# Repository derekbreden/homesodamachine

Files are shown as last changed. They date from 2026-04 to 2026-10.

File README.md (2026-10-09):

# Home Soda Machine

A kitchen appliance that dispenses real Pepsi-made diet soda — Diet Mountain Dew, Diet Pepsi, Pepsi Zero Sugar — cold and carbonated, from a faucet. Turn the handle, soda comes out.

The public face of the project is **[homesodamachine.com](https://homesodamachine.com)** — what this is, the 3D viewer, and a single signup form to be notified when units are available. This repository is the working substrate behind that.

The prototype that proves the dispense path is in Derek's kitchen today — a Lilium under-counter carbonator with peristaltic pumps injecting flavor concentrate into the dispensed water. The project's biography lives in [`biography/`](/biography/) — [`2026-04-05.md`](/biography/2026-04-05.md) (origin story: failed SodaStream, the business-license wall, the AI design wall) and [`2026-05-23.md`](/biography/2026-05-23.md) (vision into work: welding, marketing, the engineering).

The product under development is an integrated under-counter soda machine — custom-fabricated 316L stainless carbonator, harvested ice-maker refrigeration loop, foam-insulated cold core, two flavor reservoirs, all behind a single 120 VAC cord and one CO2 line. The machine as it stands, subsystem by subsystem: [`hardware/README.md`](/hardware/README.md). Where it is going and what done looks like: [`future/README.md`](/future/README.md). Who it is for: [`marketing/target-market.md`](/marketing/target-market.md); the cabinet it has to fit: [`marketing/install-envelope.md`](/marketing/install-envelope.md).

## What's where

| Path | Contents |
|---|---|
| [`biography/`](/biography/) | Project biography by chapter — `2026-04-05.md` (founding), `2026-05-23.md` (vision into work) |
| [`hardware/`](/hardware/) | The integrated soda machine under development — CAD scripts, [`bom.md`](/hardware/ledger/bom.md), [`purchases.md`](/hardware/ledger/purchases.md), [`assembly/`](/hardware/assembly/) procedures, printed parts, wiring schedules |
| [`firmware/`](/firmware/) | ESP32 + ESP32-S3 firmware: the main board, the machine display and the faucet display of the soda machine under development, the bare-board bench rig, and the weld rotator — see [`firmware/README.md`](/firmware/README.md) for which tree runs where. |
| [`web/`](/web/) | homesodamachine.com — Node server, CAD viewer — see [`web/README.md`](/web/README.md) |
| [`ios/`](/ios/) | iOS companion app (BLE bridge, settings, usage stats) |
| [`android/`](/android/) | Android companion app |
| [`brand/`](brand/README.md) | On tap faucet identity, Big Blue palette, app icons, wordmarks, and shared asset generation |
| [`marketing/`](/marketing/) | Target market analysis, [Lincoln sales and installation](marketing/lincoln/README.md), unboxing brief, video scripts |
| [`business/`](/business/) | Incorporation, regulatory (UL 943, ASSE 1022) |
| [`future/`](/future/) | Where the project is going — the vision and the plan in [`README.md`](/future/README.md), and the desires not yet committed to plans in [`pie-in-the-sky/`](/future/pie-in-the-sky/) |
| [`tools/`](/tools/) | CadQuery venv, render scripts, measurement utilities |

Agents and collaborators landing in this repo: [`CLAUDE.md`](/CLAUDE.md) is the entry point.

## License

MIT

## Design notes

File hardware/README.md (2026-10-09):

# Hardware

The soda machine's physical design — the integrated under-counter unit that consolidates carbonator, refrigeration, flavor reservoirs, pumps, valves, and electronics into one enclosure.

This page is the design narrative and the map. The narrative describes the machine subsystem by subsystem and points at the companion docs and part directories that specify each one; it carries no specifics itself. Where the machine is going, and what done looks like, is [`/future/README.md`](/future/README.md). Who it is for is [`/marketing/target-market.md`](/marketing/target-market.md).

## The soda machine

The soda machine is an integrated under-counter unit. It packs the carbonator, its refrigeration loop, both flavor reservoirs, the pumps and valves, and the electronics into one enclosure behind a single 120 VAC cord, with the tap-water inlet at the rear and the CO2 cylinder standing beside the machine on a short tether. The prototype under the counter has proven the dispense path — two flavors of Pepsi-made concentrate injected into cold carbonated water, press the lever and soda comes out. What this build adds is the cold carbonated water itself: the machine carbonates and refrigerates its own. What stays above the counter is a faucet and a small display; the rest is under the sink.

This is the **thin** machine: tall and narrow, built around one bound. The cold core is turned a quarter turn so its short axis runs across the cabinet, and nothing else in the machine is as wide, so nothing else sets the width. What the turn buys is a column of height above and ahead of the core. The space it is built for is in [`/marketing/install-envelope.md`](/marketing/install-envelope.md).

Read the machine from its cold center outward and from the back of the box forward. A **cold core** fills the back-bottom of the enclosure — a stainless carbonator, an evaporator coil wound around it, and the two flavor reservoirs nested in foam around it, where they pre-chill. Forward of the core are the compressor and the pumps and valves; above it, the electronics and the water deck; over them the flavor funnel. The carbonated-water line runs straight up through the countertop to the faucet. The sections below take the cold core **inside out** and the enclosure **back to front**.

### Carbonation

The carbonator is a custom 316L stainless pressure vessel standing vertically, with four NPT ports in two identical plates. The top water-inlet elbow carries a small jet that sends filtered tap water through the CO2 headspace into the water below. CO2 enters through a plain bottom port, carbonated water leaves through the other bottom port, and a dedicated pressure-relief valve guards the top. Temperature, CO2 pressure, jet mixing and refill timing together determine the carbonation delivered to the glass. The water level inside is read without piercing it — a magnet rides on an internal rod and external reed switches see it through the wall.

The selected diaphragm pump is the received [G Ganen sample](/hardware/reference/g-ganen-pump/README.md). The enclosure uses its measured rigid housing and ports, with four identical nominal 7 mm rubber feet at the selected rail-end stations. Installed discharge points toward enclosure −X. [Print readiness](/hardware/printed-parts/enclosure/print-readiness.md) records what the complete enclosure trial prints and what the bench has accepted. The Mean Well IRM-90-12ST supply is the current reference. The [water-inlet jet](/hardware/assembly/water-inlet-jet.md) is a drilled 316 cap welded onto the existing elbow's male tip; its fit and full root fusion require physical qualification. [Acceptance and burn-in](/hardware/assembly/acceptance-and-burn-in.md) establish actual refill, restart and first- and successive-glass performance. [Carbonation Plan B](/future/carbonation-plan-b.md) maps a measured shortfall to a conditional change.

Carbonator fabrication, the hydro-test, the passivation, and the working pressure are in [`/hardware/assembly/pressure-vessel.md`](/hardware/assembly/pressure-vessel.md), with the end-cap cut parts in [`/hardware/cut-parts/carbonation/`](/hardware/cut-parts/carbonation/) and the bench fixture that turns the tube under the welder in [`/hardware/assembly/weld-rotation-rig.md`](/hardware/assembly/weld-rotation-rig.md). The full water and CO2 plumbing — every fitting, the check valves, the beverage backflow preventer, the two-stage CO2 regulation — is in [`/hardware/assembly/internal-plumbing.md`](/hardware/assembly/internal-plumbing.md), with the joints the foam buries in [`/hardware/assembly/cold-core.md`](/hardware/assembly/cold-core.md), and the valve-and-fluid topology in [`/hardware/topology/fluid-topology.md`](/hardware/topology/fluid-topology.md). The parts themselves, and their order status, are in [`/hardware/ledger/`](/hardware/ledger/).

The [gun orientation scene](/hardware/assembly/weld-position.md) shows the tube,
recessed endcap and gun, with roll about the tangent at the joint.

### Refrigeration

The cold comes from a refrigeration loop harvested from a countertop ice maker — its compressor, condenser, fan, capillary tube, and drier kept in service, with a copper coil wound around the carbonator doing the evaporator's work. Firmware cycles the compressor against temperatures read at the carbonator wall and the coil, with a freeze cutout. The refrigerant is a natural hydrocarbon, vented and recharged through a permanent service valve.

The teardown, the recharge and its charge mass, and the brazing safety are in [`/hardware/assembly/refrigerant-loop.md`](/hardware/assembly/refrigerant-loop.md); the donor units and the keep-or-discard plan in [`/hardware/reference/ice-maker/README.md`](/hardware/reference/ice-maker/README.md); the coil winding in [`/hardware/printed-parts/cold-core/coil-mandrel/`](/hardware/printed-parts/cold-core/coil-mandrel/). The refrigerant's regulatory standing is in [`/business/regulatory.md`](/business/regulatory.md).

### Cold core (inside out)

Read it inside out: the carbonator; the evaporator coil bonded to its outside; the foam shell's inner wall foamed against the coil; the two flavor reservoirs nested in that foam, where they pre-chill in the gradient between the near-freezing core and the cabinet air; the foam shell's outer wall, foamed again. The reservoirs are vented printed parts, not pressure vessels — sized for a refill of concentrate, and level-sensed the same way the carbonator is.

The carbonator and reservoirs use the [one-piece ASA Aero float](/hardware/printed-parts/cold-core/magnetic-float/all-aero/README.md), 36 × 28 mm with an inserted RC62 at its midplane. Its [shared guide datums and reed calibration](/hardware/printed-parts/cold-core/magnetic-float/all-aero/installation.md) set the 20 mm inside-wall rod spacing. This is a trial article; pressure life and liquid compatibility remain unqualified.

The layered build is in [`/hardware/assembly/cold-core.md`](/hardware/assembly/cold-core.md). The shells and the pour-in-place foam are in [`/hardware/printed-parts/cold-core/foam-shell/`](/hardware/printed-parts/cold-core/foam-shell/), with [`foam-cap/`](/hardware/printed-parts/cold-core/foam-cap/) and [`foam-assembly/`](/hardware/printed-parts/cold-core/foam-assembly/). The reservoirs — their floor and bulkhead, their filtered vent, their reed-and-float level column, their watertight printing — are in [`/hardware/printed-parts/cold-core/reservoir/`](/hardware/printed-parts/cold-core/reservoir/). The relief-valve shroud is in [`prv-shroud/`](/hardware/printed-parts/cold-core/prv-shroud/).

### Flavor

Two peristaltic pumps draw flavor from the chilled reservoirs and inject it at the gooseneck alongside the carbonated water; each flavor is primed and valve-locked between pours. The pumps run forward only, and a valve manifold selects the fill, dispense, and clean-in-place paths. Four pump-side tees float on their tubes, their branch collars journalled in the tee wall; four bowed tee-to-valve stubs and four tee-side hairpin ends flex as the tees travel while their other ends remain on the fixed valve rows. Each reservoir fills from the shared silicone funnel on top, nominally [455 mL](/hardware/printed-parts/zone-c/funnel/README.md). The clean cycle runs in software.

The canonical valve-state truth table, with the manifold and tray diagrams beside it, is in [`/hardware/topology/fluid-topology.md`](/hardware/topology/fluid-topology.md). How a valve is held on a printed face is in [`/hardware/printed-parts/valve-seat/`](/hardware/printed-parts/valve-seat/); the pumps in [`/hardware/printed-parts/enclosure/pump-tray/`](/hardware/printed-parts/enclosure/pump-tray/) and the pump cartridge they ride out on in [`enclosure/`](/hardware/printed-parts/enclosure/enclosure/); the funnel in [`/hardware/printed-parts/zone-c/`](/hardware/printed-parts/zone-c/). The four bowed stubs' figures in the topology are exposed developed paths across sleeve-face gaps, not tube-blank cut lengths. The valve-side insertion depths are bench-fit as each tube blank is made. Derek’s [physical collet observations](/hardware/reference/tee-connector/README.md#observed-push-connect-action) establish the release and relocking action; the assembled unit’s dry cycle checks release and reconnection. The reservoir level-sensing pattern is in [`/hardware/printed-parts/cold-core/reservoir/level-sensing.md`](/hardware/printed-parts/cold-core/reservoir/level-sensing.md). One pump serving N flavors on a single line, switching by reverse-purge and re-prime, is a desire captured in [`/future/pie-in-the-sky/single-pump-flavor-switching.md`](/future/pie-in-the-sky/single-pump-flavor-switching.md).

### Enclosure (back to front)

The enclosure stands in the cabinet beneath the sink, in the slot beside the disposal that [`/marketing/install-envelope.md`](/marketing/install-envelope.md) describes. Read it back to front. The cold core is yawed a quarter turn and seated in the back-bottom corner, flat on the floor and flush at the side walls; the diaphragm pump runs front to back over its lid and is what the rear wall stands off. The band above the core is the service bay: the diaphragm pump down the middle, the electronics bay against the +X wall, the water deck in the −X lane. The compressor stands upright on the floor at the front, bolted to the slab, with the condenser beside it and the **machine corridor** behind — the band the refrigerant loop turns in on its way to the core, and the one the manifold's cross-machine lines run along. The condenser's airflow crosses the cabinet: in through the grille on one side face, out the other. The top-front arris is rounded wall to wall, with the machine display let into its sloped plane; the funnel takes the top wall's full width behind it. The cabinet prints as four telescoping quadrants that cross-pin with screws from the side faces. The pump cartridge and its top clamp ride in the front bay; behind them a fixed release plate fronts four tee journals. At release the collets bear fully depressed against the fixed plate; at connected they stand fully extended, 0.5 mm from the plate. Pulling the cartridge draws the tees to the plate, which holds the collets open while the four tubes leave. No face is a panel of its own. The **+Y wall of back-top** lands every connection the machine makes to the world — the water inlet, the CO2 inlet, the AC cord, the signal jack and the umbilical — one row above the deck. The front wall's one opening is the bay, and the pump cartridge's own face closes it.

The silhouette, the zoning, and what each face carries are in [`/hardware/printed-parts/enclosure/README.md`](/hardware/printed-parts/enclosure/README.md). The split-printable box and its joint are in [`enclosure/`](/hardware/printed-parts/enclosure/enclosure/), the packed assembly in [`manifold-layout/enclosure_assembly.py`](/hardware/manifold-layout/enclosure_assembly.py). The +Y wall of back-top's connection inventory is in [`y-wall-of-back-top/`](/hardware/printed-parts/enclosure/y-wall-of-back-top/), the serialized nameplate in [`nameplate/`](/hardware/printed-parts/enclosure/nameplate/). The mechanical assembly of the whole is in [`/hardware/assembly/enclosure-mechanical.md`](/hardware/assembly/enclosure-mechanical.md). What placement answers to is [`design-pressures.md`](/hardware/design-pressures.md).

### Electronics and power

A single 120 VAC cord enters the +Y wall of back-top. A 12 V supply makes the low-voltage bus that runs the diaphragm pump, the peristaltic pumps, the solenoid valves, the condenser fan, the displays, and the sensors; the logic rails are made on-board. The compressor switches on the AC side; the fan and the 12 V loads switch low-side, firmware-gated. The whole electronics bay — the PSU, the relays, the AC distribution and ground bus, the main board, and the DC distribution — stands down the +X wall in the band above the cold core, feet on the foam cap's lid, each module turned so its own mounting plane faces the wall and bolted to printed bosses reaching in off it, with the water deck in the lane beside them. There is no tray under any of it.

The run-by-run AC schedule is in [`/hardware/wiring/ac-wiring-schedule.md`](/hardware/wiring/ac-wiring-schedule.md), and the power, pinout, and valve-control topology in [`/hardware/wiring/`](/hardware/wiring/). The bench build of the electronics, and the wiring procedure that follows it, are in [`/hardware/assembly/electronics-bay.md`](/hardware/assembly/electronics-bay.md) and [`/hardware/assembly/wiring.md`](/hardware/assembly/wiring.md). The main board — one JLCPCB-assembled PCBA, no plug-in modules — is in [`/hardware/pcb/`](/hardware/pcb/); its bench mount, which does not ship, is in [`/hardware/printed-parts/electronics/`](/hardware/printed-parts/electronics/).

### Safety

Simply having a 1022 already puts us ahead of most of these products. A 1022 that vents into the bowl at the faucet would be the only home arrangement I've found where the vent's discharge is defined, drained and visible.

Three hazards are designed around independently. The compressor's terminal block and clip-on PTC start relay remain under the R-600a donor's own moulded cover; the hydrocarbon refrigerant is watched by a gas sensor low in the cabinet that gates the remotely mounted compressor relay, and backstopped by a thermal fuse in the compressor's own AC primary. The carbonic-acid backflow path is held by a beverage backflow preventer whose vent runs through a dedicated white 4 mm LLDPE line to a visible outlet over the sink bowl near the faucet joint. The plumbed machine's mains and ground-fault posture, the refrigerant charge limits, and the unit markings are consolidated in one place.

The whole safety and regulatory posture is in [`/business/regulatory.md`](/business/regulatory.md), which carries the qualification still owed on the retained donor terminal cover; the refrigerant-handling and brazing safety in [`/hardware/assembly/refrigerant-loop.md`](/hardware/assembly/refrigerant-loop.md) under "Safety". An integrated ground-fault (GFCI) module is a deferred desire, captured in [`/future/pie-in-the-sky/gfci.md`](/future/pie-in-the-sky/gfci.md).

### User-facing surfaces

Above the counter, the faucet lever pours, and the faucet display at the end of the gooseneck shows the selected flavor and switches it by touch. On the machine's rounded top-front, angled up toward the standing user, the machine display is the configuration surface, over the flat face that is the pump cartridge's own. Flavor is refilled from the top: pour into the silicone funnel. For cleaning, lift it straight out; its plug slides off the raw tube stub held in the drain elbow. Press the plug into the frame to refit it until the brim seats. The pumps are reached from the front instead — pull the pump cartridge and both are in your hand. The pumps connect through a magnetic pogo contact pair between the cartridge's flat back and the bay bulkhead, which parts as the cartridge leaves and mates as it seats; the fixed lead returns to J13 through the cable clip near the ridge wall's +X edge. To return the cartridge, present the four pump tubes through the release plate and seat it.

The faucet's printed parts — the faucet shell, display cover, above-counter plate, above-counter gasket, o-ring and [umbilical organizer](/hardware/printed-parts/faucet/umbilical-organizer/README.md) — are in [`/hardware/printed-parts/faucet/`](/hardware/printed-parts/faucet/), over the cut [`under-counter plate`](/hardware/cut-parts/faucet/). The displays' reference geometry is in [`/hardware/reference/waveshare-43b-display/`](/hardware/reference/waveshare-43b-display/) and [`/hardware/reference/touch-flo-faucet/`](/hardware/reference/touch-flo-faucet/); the facet the machine display is let into, and the pump cartridge under it, in [`/hardware/printed-parts/enclosure/enclosure/README.md`](/hardware/printed-parts/enclosure/enclosure/README.md); the funnel in [`/hardware/printed-parts/zone-c/README.md`](/hardware/printed-parts/zone-c/README.md). What the customer does on install day is drawn in the [install guide](/hardware/install-guide/README.md). The behavior these surfaces drive is firmware — [`/firmware/`](/firmware/).

### Build order

The sequence the whole machine is built in is the dependency chain of the procedure docs in [`/hardware/assembly/`](/hardware/assembly/), with the skilled-hand tasks summarized in [`handwork.md`](/hardware/assembly/handwork.md): carbonator, cold core, refrigerant loop, then three benches that run in parallel with that chain and feed the chassis — cable assemblies, electronics bay, faucet and umbilical — then the loose-front-top manifold, enclosure closure, the remaining internal plumbing, wiring, commissioning, burn-in, pack and ship.

[`internal-plumbing.md`](/hardware/assembly/internal-plumbing.md) §3 begins before enclosure closure because `enclosure-front-top` is the assembly fixture. Its order is bare tees loaded into the tee wall's journals; aft valves raised from the underside and pressed into their sockets; fore valves and four bowed flex stubs. The pump cartridge goes in only after the box closes. The rest of internal plumbing follows [`enclosure-mechanical.md`](/hardware/assembly/enclosure-mechanical.md), and [`wiring.md`](/hardware/assembly/wiring.md) takes a chassis that already carries its plumbing. [Letter shop guides](/hardware/assembly/guides/README.md) illustrate drilling and cutting, molds, refrigeration, and the carbonator weld operation.

The Lillium-fed build, the flavor side in the enclosure with none of the cold core, is [`lillium-cutover.md`](/hardware/assembly/lillium-cutover.md).

## Layout

| Path | What's there |
|---|---|
| [`design-pressures.md`](/hardware/design-pressures.md) | What the machine is optimised for and what it is not. Placement decisions answer to this: volume and assemblability are optimised, field service and disassembly are not. |
| [`concerns.md`](/hardware/concerns.md) | Every concern raised about the machine, by stage of its life: answered, with its evidence, or open, with what exists so far. |
| [`mechanical-qualification/`](/hardware/mechanical-qualification/README.md) | Current mechanical evidence and qualification needs: fasteners, joint locations, deposited print structure, retained clamp force, handling and endurance. Links accepted physical records and controlled profile comparisons. |
| [`ledger/`](/hardware/ledger/) | Bookkeeping. [`purchases.md`](/hardware/ledger/purchases.md) is the source-of-truth capex ledger; [`bom.md`](/hardware/ledger/bom.md) (per-unit parts), [`tools.md`](/hardware/ledger/tools.md) (active tooling), and [`inventory.md`](/hardware/ledger/inventory.md) (spares / abandoned / donor / diagnostic stock) are views over it. Three more price time rather than parts: [`labor.md`](/hardware/ledger/labor.md) (attended minutes per unit), [`machine-time.md`](/hardware/ledger/machine-time.md) (hours a machine is occupied per unit), and [`build-time.md`](/hardware/ledger/build-time.md) (seconds a generator run takes, which is what a change to this repo costs rather than what a soda machine costs). |
| [`assembly/`](/hardware/assembly/) | Production procedures, one doc per subsystem, plus [`handwork.md`](/hardware/assembly/handwork.md) (the skilled-hand task summary). |
| [`service/`](/hardware/service/) | Procedures run on a finished machine rather than a bench: [`pump-replacement.md`](/hardware/service/pump-replacement.md) and the dry cycle it runs first. |
| [`printed-parts/`](/hardware/printed-parts/) | FDM parts: CadQuery generators (`*.py`) + exported `*.step` + sidecars. Includes `cadlib/` (shared geometry helpers), `cold-core/`, `electronics/`, `enclosure/`, `faucet/`, `refrigeration/`, `valve-seat/`, `zone-c/`. |
| [`cut-parts/`](/hardware/cut-parts/) | Laser-cut sheet parts: `*.dxf` outlines + sidecars (carbonation end-caps, under-counter plate). |
| [`manifold-layout/`](/hardware/manifold-layout/), [`cold-core-layout/`](/hardware/cold-core-layout/), [`faucet-layout/`](/hardware/faucet-layout/) | The assemblies the parts above stand in, each written as one multi-solid STEP: the packed machine, the core one frame further in, and the above-counter column. `/3d` browses the tree these head — the machine and the faucet as its two cards, and the machine stands the core's own bodies, so opening it is already being inside the core. |
| [`off-the-shelf-parts/`](/hardware/off-the-shelf-parts/) | Reference geometry for purchased parts modelled into assemblies. |
| [`reference/`](/hardware/reference/) | Imported / harvested reference STEPs (factory faucet, solenoid, ice-maker, fittings). Not fabricated by this project — no sidecars. |
| [`topology/`](/hardware/topology/) | Fluid + valve topology, including the canonical valve-state truth table. |
| [`wiring/`](/hardware/wiring/) | Wiring schedules, pinouts, and power topology diagrams. |
| [`battery-backup/`](/hardware/battery-backup/) | Mains-outage dispense ride-through: an architecture the BOM, wiring and firmware do not yet carry. |
| [`install-guide/`](/hardware/install-guide/) | The bound install guide that ships in the install kit beside it. |
| [`snapshots/`](/hardware/snapshots/) | Dated, point-in-time records (build-readiness audit, tapping plan, fill-from-funnel plan). **Frozen, not living docs** — re-run produces a fresh dated file rather than editing these. |
| [`scripts/`](/hardware/scripts/) | Project Python tooling. The instruments: [`probe.py`](/hardware/scripts/probe.py) asks the placed machine a geometry question instead of reasoning about it — where a body is, how close two come, what a volume runs into, how far a line runs, where there is room for one, what a pick copied out of the viewer names, and where a piece of a routed line can stand; [`fit.py`](/hardware/scripts/fit.py) asks the same of a body that is not placed yet, carried to a candidate pose; [`lanes.py`](/hardware/scripts/lanes.py) enumerates every corridor a run could take between its two fixed mouths at a stated clearance floor, holding every body still, and reports each one's tube, corners, tightest clearance, lowest z and the sub-assembly its legs lie on without ranking them. Each carries a `selftest`. Then `_cadq_export.py` (the shared atomic STEP/DXF/PDF export helper imported tree-wide) and the doc-sync / totals generators that maintain the `ledger/` docs. |

## Where the solids are

    node web/scripts/fetch-cad-artifacts.mjs              # the solids the pointer file names, onto this disk

A generated `.step` is on this disk and in no index. [`cad-artifacts.json`](/hardware/cad-artifacts.json) names each one by sha256, the release asset carrying them, and the commit each came from — `source.commit` for the bundle, and an `unproven` entry naming the uncommitted paths a pack was cut beside and the members they reach, since a solid mid-edit still ships. [`tools/cad-artifacts/pack.py`](/tools/cad-artifacts/pack.py) builds and points at one, and the deploy runs the fetch above (`render.yaml`). A build cuts them too, so a checkout that runs one needs no fetch. The three harvested solids under [`reference/`](/hardware/reference/) have no builder here and are in the index.

## The design loop

    source → changed solid → local view → pointer moved → /3d

The local render and the deployed viewer are two stops on one geometry path. [`tools/look.sh`](/tools/look.sh) opens a generated STEP from this disk through the same `/3d` viewer the headless renderers drive. [`pack.py --write`](/tools/cad-artifacts/pack.py) packages the generated solids on this disk; after its pointer file is committed and pushed, Render fetches that bundle and `/3d` serves it. Each commit runs [`publish_now.py`](/tools/publish_now.py) from `.githooks/post-commit`, which publishes the solids on this disk and moves the pointer file. The solid an agent judges locally is the solid that goes in front of Derek.

A repository-wide build is not a viewing boundary. A generator, focused Bazel target, [`probe.py`](/hardware/scripts/probe.py), or [`fit.py`](/hardware/scripts/fit.py) answers the current design question; the next local picture follows it immediately. Broader builds and checks answer broader questions when those questions arise. The iteration speed that matters is the time from an edit to the next informed look — first by the agent, then by Derek.

## What a build costs

    bazelisk build //:everything                          # every generator whose inputs moved
    tools/cad-venv/bin/python tools/bazel/sync_tree.py    # what the tree does not carry yet

For a focused dirty-tree build:

    targets=$(tools/cad-venv/bin/python tools/bazel/affected.py --artifacts)
    bazel build $targets
    tools/cad-venv/bin/python tools/bazel/sync_tree.py --write --solids-only --targets "$targets"

ONE ACTION PER STEP, EACH HOLDING WHAT IT DECLARED AND NOTHING ELSE. What it declared is what
a run of it was watched reading — `tools/bazel/trace_inputs.py` installs an audit hook, runs
the generator once, and keeps every path under this repo it opened, including the ones handed
to a tool it starts. The median step declares nine files; `_cable_assemblies_sync` declares
six, and the assembly syncs that import the machine to reach its constants declare eighty. The
graph is `tools/bazel/graph.json`; `tools/bazel/gen_build.py` writes `BUILD.bazel` from it.

A step is usually one generator. Four are several: `docgen` lets more than one script keep a
doc's `[value](NAME)` figures, each managing its own names, so `faucet_shell.py` and
`under_counter_plate.py` both write `ASSEMBLY.md` and are one action. `bazel` needs
one action per file, and `inventory._together` is what groups them.

`bazel-bin/` is where a build lands. The tree commits its docs and holds ignored solids long
enough for the content-addressed bundle to publish them, because a reader at `/3d` and a shop
printing a part both need the same bytes. `sync_tree.py` carries every declared output over;
a tree it has nothing to say about is a tree holding the artifacts its sources make.

WHAT AN EDIT COSTS IS THE STEPS THAT DECLARED THE FILE, and that is a count, not a guess.
`_boxes.py` is declared by 95 of the 99 steps, so it is the worst case the tree has:

| an edit to `_boxes.py` | steps | wall |
|---|---|---|
| a comment written into it | **1** — `pysrc` alone | **1.8 s** |
| a line of code | 95 | 406 s |

| | wall |
|---|---|
| the whole tree, nothing moved | **0.4 s**, no action run |
| whether anything is owed — `--check_up_to_date` | **0.3 s**, no action run |
| every step rerun, the kept work standing | 88 s, 41 s of critical path |
| every step rerun, the kept work regenerating | 386 s, 219 s of critical path |

The last two are the same 99 actions and differ only in whether `.cache/` already holds the
shapes they cut. A geometry edit pays the second on the bodies it moved and the first on the
rest. All of these were taken on a quiet machine; a reading taken while another build is
running is roughly half speed for want of cores, and is a ceiling rather than a figure.

A BYTE IS WHAT DECIDES A RERUN, and a comment is not a byte a step reads. `tools/bazel/pysrc.py`
lays every Python source down with its comments out of it — a line carrying no code is gone,
and the code lines come through verbatim and in order — and the steps declare that copy rather
than the file. So writing a comment moves one short action, its output lands on the bytes Bazel
already built against, and nothing under it runs. What comes out parses to what went in, and
`pysrc` asserts that per file before it writes: the same reading `_realized.code_digest` takes,
put where Bazel can see it.

The 32 generators whose own docstrings hold `[value](NAME)` figures are handed their file raw,
because the run rewrites what it was given and `sync_tree` carries that back into the tree. A
step that actually starts Node is also handed `:node-packages`, which globs `tools/render/` and
`web/` in whole.

A line number in a sandbox traceback is that copy's, not the tree's. The line it names is in
the tree, found by its text.

AND AN ACTION HOLDS THE KEPT WORK. `.cache/` is the shapes `_realized` keeps, the meshes
`_meshes` tessellates and the optimal boxes `_boxes` measures; `.bazelrc` mounts it into every
action and `_realized.key` mixes in `HSM_INPUT_DIGEST`, a hash over the solids the action was
given. The import walk covers the Python and that digest covers the other half — a solid loaded
off disk is not an import, and `enclosure.py` makes no `import_step` call of its own while its
action declares 28 solids it reaches through what it imports.

A SOLID ONE GENERATOR CUTS AND THE NEXT LOADS IS AN EDGE LIKE ANY OTHER HERE. `foam_assembly`
reads `foam-cap-top.step` from `//:foam-cap` and `enclosure_assembly` reads
`foam-assembly.step` from `//:foam-assembly`; neither can fall back to the older copy fetched
from the artifact pointer file. OCCT opens these below Python, so `_cadq_export.import_step` records the
paths and `gen_build.py` resolves each one to its producer output.

A picture is the same picture every run. Every renderer in `tools/render/` reads the frame
back off the canvas in the task that drew it (`browser.js` `frameBuffer` carries why), so
nothing here is a race and a redraw of unmoved geometry lands byte-identical — eight runs of
one scene and eight of one part, one hash each.

A view of any STEP, from any angle, is `tools/look.sh` — drawn when someone asks for one, so
there is none of it in the tree to go stale.

WHAT THE ACTIONS RUN WITH IS THE MACHINE'S, not the tree's. `tools/cad-venv` holds the
interpreter and its packages, `node_modules` the renderer's, and `rsvg-convert` and `blender`
come off the brew prefix — `.gitignore` holds the first two and the last two are not in the
repo at all. `.bazelrc` names both roots as mounts and puts them on every action's PATH. A
checkout on another machine builds when those are installed there and not before.

AND `blender` INSTALLED IS NOT THE WHOLE OF WHAT THE LINE ART NEEDS. The Freestyle SVG
exporter is a downloadable extension, not part of Blender, and everything `_blender_scene.py`
and `sieve_scene.py` ask it for is a property it ADDS to the scene when it registers —
`linestyle.use_export_strokes`, and the `scene.svg_export` group. A Blender without it is a
Blender the line art cannot run on:

```
blender --background --online-mode --command extension install -s -e freestyle_svg_exporter
```

`BLENDER_USER_RESOURCES` decides where that lands and where a run looks for it, so `.bazelrc`
passes the variable through to every action rather than stating a path — unset on a machine
whose extensions are already under the default user path. Both scene scripts check the enable
and exit non-zero naming the extension, because `addon_utils.enable` does not raise when the
module is absent: it prints one line and returns None, and the miss surfaces a hundred lines
later as an `AttributeError` with Blender itself exiting 0.

TWO THINGS THE BUILD DOES NOT GUARANTEE, both named where they stand:

- **A `.step.mesh` is not a declared output.** `_cadq_export` tessellates best-effort — a
  payload must never break an export — and a Bazel output is one the action must produce or
  fail. The two are opposite promises. So no action writes one: `sync_tree` carries what a
  target declares, the payload is in nothing's `outs`, and `.bazelrc` sets
  `HSM_SKIP_MESH_PAYLOAD` for every action rather than tessellating a file the sandbox
  discards. The runs that keep the tree's payloads are a hand run and the dev-server watcher.
- **`//:render-scenes` carries `local` and is not sandboxed.** `render-step-posed.js` stands
  the viewer on loopback and photographs it with a headless browser, and that page loads
  `occt-import-js` off a CDN — so drawing a scene reaches the public network for a library this
  tree does not carry. Vendoring it is what would make the action hermetic. It is the one
  action here whose inputs are not all declared.

Inside one run:

| phase | wall |
|---|---|
| derive + audit — `build_enclosure_assembly`, then the card | 8.7 s |
| — of which `_boxes.boxed`, 1372 calls against the disk-kept six | 0.55 s |
| OCCT STEP write, 21 MB | 1.3 s |
| canonicalise — renumber 382,700 entities | 3.7 s |
| tessellate the `.mesh` payload | 1.6 s |
| one thumbnail, drawn off the payload | 3 s |
| one thumbnail, drawn off the STEP with no payload beside it | 16 s |

The export and render rows are timed at `189e46a0`; the two derive rows at `7101d08c`.

## Part metadata sidecars

Every fabricated part has a JSON sidecar next to it recording material + thickness + process. The dev viewer reads these to extrude DXF outlines into real 3D plates; tooling and future agents should treat them as the source of truth for material/thickness queries.

### Naming

`<full-filename>.json`, in the same directory as the part:

```
cut-parts/foo/foo.dxf
cut-parts/foo/foo.dxf.json       ← sidecar

printed-parts/bar/bar.step
printed-parts/bar/bar.step.json  ← sidecar
```

The sidecar filename always carries the original extension (`.dxf.json`, `.step.json`), so a directory holding both a `.dxf` and a `.step` of the same basename has no collision.

### Format

```json
{
  "thickness_mm": 1.524,
  "material": "304 stainless steel",
  "process": "laser-cut",
  "notes": "optional free-form context"
}
```

- **`thickness_mm`** (number, required) — for DXF cuts this drives the viewer's `ExtrudeGeometry` so the flat outline becomes a real plate. For STEP prints / shells / tubes it is the wall thickness, kept for documentation and future tooling (the STEP geometry itself already carries full 3D shape).
- **`material`** (string) — free-form, in the spec language you'd put in a quote or order: `"304 stainless steel"`, `"316 stainless steel"`, `"PETG"`, `"PET-GF"`, `"Bambu TPU 90A"`, etc.
- **`process`** (string) — free-form. Common values: `laser-cut`, `3D-print`, `tube-bend`. Add new values as needed.
- **`notes`** (string, optional) — anything else worth knowing: stock size, supplier, why the spec was chosen, tap-engagement counts.

Pull values from the part's generator-script docstring when one exists; otherwise use the spec you ordered or printed against.

### When to update

- **Adding a part:** add the matching `.json` sidecar in the same commit. The viewer treats a DXF without a sidecar as zero-thickness and falls back to wireframe.
- **Changing thickness or material:** update the sidecar in the same commit as the geometry. The dev server's watcher picks up sidecar changes and hot-reloads with the new thickness, no page refresh needed.
- **Renaming or moving a part:** rename/move the sidecar alongside the geometry file.

### Harvested reference parts

[`reference/`](/hardware/reference/) holds imported reference STEPs (the harvested Westbrass, valve internals) this project does not fabricate. These get no sidecars — they're multi-material, externally-spec'd parts kept only for spatial reference.

### Where this is consumed

- The dev viewer (`web/`) extrudes DXF outlines using `thickness_mm`; STEP rendering ignores the sidecar (the STEP is already 3D). See `web/lib/viewer-routes.js` (`/api/dxf` returns each DXF's path alongside its sidecar fields).
- Future tooling (BOM generators, render-dxf, manufacturing quotes) should read the sidecar rather than re-parsing docstrings.

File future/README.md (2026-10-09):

# Future

This directory is what the project is for and where it is going. This page carries the
vision and the plan; [`pie-in-the-sky/`](/future/pie-in-the-sky/) carries the desires that
have no plan yet. Everything else in the tree describes what is: the machine as it stands
is [`/hardware/README.md`](/hardware/README.md), who it is for is
[`/marketing/target-market.md`](/marketing/target-market.md).

## What the machine is for

A person walks to their kitchen sink, turns a handle, and a glass fills with Diet Mountain
Dew — as cold and as carbonated as the can, and colder and fizzier than most. They never
buy a can again. That is the whole of it.

The alternatives on the market do not do this. Canned soda means hauling twenty-four to
forty-eight cans a week from store to car to kitchen, and running out. Home carbonation
means carbonating warm water into a bottle that is flat before it reaches the glass, which
is why the machines sell enormously and get used twice. The gap is refrigeration: cold water
holds carbonation and warm water does not, and no consumer product refrigerates and
carbonates and dispenses on demand.

The flavor is not a substitute. Pepsi sells its own formulations as SodaStream-compatible
concentrate to anyone, so a machine that injects it dispenses the brand rather than an
approximation of it. What is missing is the machine.

## What done looks like

Three marks, in order. Each one is finished when a physical thing exists, not when a
document says so.

**One. The machine pours in Derek's kitchen.** One appliance, built end to end from this
tree — carbonator welded and hydro-tested, loop brazed and charged, core foamed, box
printed, board flashed, faucet plumbed through the counter — standing under his own sink
where the prototype stands now, pouring both flavors daily for a month without being
opened. Until this exists the tree describes a machine that has never been built once.

**Two. Ten machines in ten kitchens.** Ring 1 of
[`target-market.md`](/marketing/target-market.md) "The internal plan": the first ten units
go to people Derek knows, or one degree out, at whatever price moves them. The deliverable
is not the revenue. It is ten machines in daily use by people who did not build them,
generating failures Derek did not predict, and supplier relationships priced at a run of
fifty. Ring 1 closes when the tenth unit is installed and the design is tighter than what
unit one received. Each plate those units carry is lettered and coded with the
unit's own address — [Unit links](/future/unit-links.md).

The [Lincoln sales and installation track](/marketing/lincoln/README.md) explores local
advertising, founder delivery and installation, and nearby service alongside the relationship
rings. It shares the build queue and founder hours; its local offer and pilot size remain
proposals.

**Three. The Founder Edition run.** Units 001–050 at $7,500, numbered and signed, built one
at a time by one person. This is the public plan and the price anchor; it opens when the
machine has been built enough times that the build is boring, and it closes when the
fiftieth is committed.

## What stands between here and the first mark

The build follows the order in [`/hardware/README.md`](/hardware/README.md) "Build
order". First-unit fabrication and performance qualification are part of that work.

| Owed | Where the procedure is |
|---|---|
| The water-inlet jet cap fitted, welded and physically qualified on the existing elbow | [`water-inlet-jet.md`](/hardware/assembly/water-inlet-jet.md) |
| The first production closure weld, PT-checked, hydro-tested, passivated | [`pressure-vessel.md`](/hardware/assembly/pressure-vessel.md) |
| The first refrigerant loop brazed to a carbonator and charged | [`refrigerant-loop.md`](/hardware/assembly/refrigerant-loop.md) |
| The first cold core foamed in place around a welded carbonator | [`cold-core.md`](/hardware/assembly/cold-core.md) |
| The whole enclosure printed as one set of quadrants that close on each other | [`enclosure-mechanical.md`](/hardware/assembly/enclosure-mechanical.md) |
| One appliance plumbed, wired, commissioned, and burned in for eight hours | [`internal-plumbing.md`](/hardware/assembly/internal-plumbing.md), [`wiring.md`](/hardware/assembly/wiring.md), [`acceptance-and-burn-in.md`](/hardware/assembly/acceptance-and-burn-in.md) |
| Measured refill and restart, strong carbonation in the first and successive cold glasses, and recorded recovery | [`acceptance-and-burn-in.md`](/hardware/assembly/acceptance-and-burn-in.md), [`carbonation-plan-b.md`](/future/carbonation-plan-b.md), [`model.md`](/future/model.md) |
| One faucet installed through a real countertop by the customer's own path | [`quickstart/`](/hardware/quickstart/) |

The procedures identify the remaining physical qualifications, including jet-cap fit
and weld fusion, gas-check placement, and carbonation under actual refill conditions.
The first unit uses the G Ganen pump, IRM-90 supply and enclosure. The conditional
responses in [Carbonation Plan B](/future/carbonation-plan-b.md) apply only if the
measurements identify a shortfall. The work and machine time are tracked in
[`labor.md`](/hardware/ledger/labor.md) and
[`machine-time.md`](/hardware/ledger/machine-time.md).

## What the tree is for

The repository is a manufacturing system, and that is deliberate. It cuts the parts, prices
them, names them, and publishes what it holds, so that the fiftieth unit costs what the
ledgers say and not what the first one taught. A generator that draws a part also writes its
own documentation, its figures, and the card the operator builds from, so a figure in a
document is read off the part rather than typed beside it. A check runs when someone asks
the question it answers, not on every commit or build.

The risk this creates is the obvious one. A tree that can be improved forever will be, and
improving it feels like progress in a way that welding does not. The marks above exist to
name the difference. Nothing in this repository is finished by a commit.

## No dates

There are none here, and there are none anywhere in this tree. A mark is finished when the
physical thing exists, and the record of when that happened is written after it happens —
[`updates/`](/updates/) and [`biography/`](/biography/) are where it lands. What this page
holds is the order the marks come in and what each one is owed, which is a plan; a date
would be a guess dressed as one.

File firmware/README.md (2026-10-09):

# Firmware

Five source trees, each its own PlatformIO environment in [`/platformio.ini`](/platformio.ini), each running on its own board.

| Tree | Env | Runs on | Machine |
|---|---|---|---|
| `src_appliance/` | `appliance` | the main board's WROOM (U1) | the soda machine |
| `src_pcba_bench/` | `pcba_bench` | the main board's WROOM (U1) | none — a bare board on the bench |
| `src_front/` | `esp32s3_front` | Waveshare ESP32-S3-Touch-LCD-4.3B | the soda machine |
| `src_faucet/` | `esp32s3_faucet` | Waveshare ESP32-S3-Touch-LCD-1.47 | the soda machine |
| `src_weld_rotator/` | `weld_rotator` | ESP32-DevKitC-32E + DM542T | the cap-weld bench fixture |

Two of them run on the main board, and only one of the two ships inside a machine.

**`src_appliance/` is the soda machine's own firmware** — the state machine, the thermal loop, the dispense, persistence, the links to both displays ([`src_appliance/README.md`](src_appliance/README.md)). It boots to the state [`acceptance-and-burn-in.md`](/hardware/assembly/acceptance-and-burn-in.md) opens against — build ID printed, every actuator parked dark — and brings up J9 and J3. What runs at the glass today is one flavor pump, the funnel fill and the clean cycle: a prime held from the 4.3B, `pump <a|b> [ms]` bounded from the console, a fill that opens a channel's funnel path and draws with its pump — held from the machine display's FILL page or run by `fill <a|b> [s]` — a clean cycle that puts tap water through the channel in rounds, in through the idle pump and out through the faucet — started from the machine display's CLEAN page or by `clean <a|b> [rounds] [s]` — and the dry cycle before a pump replacement, air swept through both channels to the faucet, from the machine display's Settings → PUMP SERVICE or by `dry`. Beside all of that the cold loop cycles relay #1 and the condenser fan against the two 1-wire probes on IO26, and the refill closes relay #2 on V-K against the carbonator's two reeds; `status` and `thermal` read both, and `sim` puts a reading at the top of either so the loops can be walked with no probe on the bench. Flavor selection from either display reaches and is persisted by the main board for the future automatic-dispense path, then mirrors to the other display. `machine.cpp` owns every actuator request; `pcba_expanders.cpp` clears and verifies both MCP23017 output banks, enables the reed pull-ups and owns the physical V-A–V-K map; `link.cpp` turns a J9 frame into a machine intent. The USB `status` command reads both expanders and all ten reeds; Prime, the pour, the fill, the clean cycle and the dry cycle are the runtime operations that open valves, one topology state at a time and at most three valves at once. The procedure it fills in is [`/hardware/assembly/firmware-and-commissioning.md`](/hardware/assembly/firmware-and-commissioning.md) §3, §6, §7 and §9; the pin map is [`pcba.tsx`](/hardware/pcb/pcba/pcba.tsx), drawn as [`/hardware/wiring/esp32-pinout.mmd`](/hardware/wiring/esp32-pinout.mmd).

Shared libraries sit under `lib/`, compiled into whichever trees include them:
[`lib/proto_link`](lib/proto_link/proto_msg.h) is the inter-board wire contract;
[`lib/machine_policy`](lib/machine_policy/machine_policy.h) is the Arduino-free actuator-plan,
safety-transition and pump-timing policy; [`lib/flavor_selection`](lib/flavor_selection/flavor_selection.h) is main board authority and persistence policy; [`lib/weld_rotator_policy`](lib/weld_rotator_policy/weld_rotator_policy.h) holds the rotator's physical ratio and every deadman transition; and [`lib/sound`](lib/sound/sound.h) is U8 — the drive on IO13, the machine's sound vocabulary,
and the volume/quiet-hours settings behind it. The machine and the bench share that one
table on purpose: a board on the line makes exactly the sounds a customer's machine makes.
Neither display carries a sounder, so every sound the machine makes is made on the main board.

Two of those libraries have their decision in a library of its own, so a host can ask it:
[`lib/sound_policy`](lib/sound_policy/sound_policy.h) is what a volume setting and a quiet
window do to a sound — including the exemption that keeps the gas alarm out of their reach —
and [`lib/echo_policy`](lib/echo_policy/echo_policy.h) is which byte off J9 is the main board's
own echo, and what a byte that is not one means. Neither reaches Arduino.

`src_pcba_bench/` is the bench rig for a **bare** board, one board per fab batch, and goes no further than the bench. It answers whether the fab built what [`pcba.tsx`](/hardware/pcb/pcba/pcba.tsx) describes — it reads every device, and behind `arm` it drives both relays, both DRV8870 pumps and the buzzer, one output at a time for 120 s so each can be metered at its connector. It also carries the buzzer's range — `ladder`, `duty`, `palette`, played once at boot — which is where the machine's alarms and acks get designed ([`src_pcba_bench/README.md`](src_pcba_bench/README.md)). It never writes `IODIR` or `GPPU` on either MCP23017, so the ten manifold valves, V-K and the condenser fan — everything behind the two expanders — stay dark, and no reed is ever read on a pull-up. It answered batch 2 on the bench: [`/hardware/pcb/pcba/bench-log.md`](/hardware/pcb/pcba/bench-log.md).

## J9 is one pair, and both ends take turns

The display link is a single differential pair — J9 is `[B, A, GND, V12]` — carrying half-duplex RS485 between the main board and the 4.3B. **Nothing arbitrates it.** U7 on the main board is an auto-direction transceiver with `/RE` tied to GND, so the main board's receiver runs while its driver does and it hears every byte it sends; [`lib/proto_link/rs485_echo.h`](lib/proto_link/rs485_echo.h) exists to strip that echo before the framer sees it.

That echo cancellation is only sound while the two ends do not talk at once. If the glass sends while the main board is replying, the two collide, the main board reads back something other than what it wrote, and the echo it is waiting for never arrives. A canceller that merely counted bytes would stay in deficit from that moment and swallow real traffic as its own echo — the main board goes quietly deaf, and the frame that gets lost is whichever one arrived next. That failure looks exactly like latency, because the sender's retry eventually gets through.

So the rule, and it is a rule rather than an optimisation:

- **The main board answers; it never interrupts.** Every frame it puts on the pair goes out inside the window immediately after one arrives. Anything the machine wants to volunteer — a prime that timed out, a bounded run that finished, the image reconcile asking both stores what they hold — is queued in [`src_appliance/link.cpp`](src_appliance/link.cpp) and flushed in that window, and so is every question the console puts to the glass. `linkPing` is the one deliberate exception, and it is a bench command with nobody expected to answer.
- **The glass sends one frame at a time.** Everything posts to the outbound queue in [`src_front/main.cpp`](src_front/main.cpp), and the next frame waits for the answer or for the turnaround window to lapse. The exception is a reply made from inside the turn that asked for it — `MSG_RESP_UI_SHOW`, `MSG_RESP_TEST_SCREEN` and `MSG_RESP_DISPLAY_USB_REATTACH` answer on the wire the main board is still holding open. One press is one frame — a button that already speaks for itself sends no separate click, and the main board makes the tick off the command it received.
- **The glass polls on an interval,** because that poll is the only window the main board has to speak in. It is the ceiling on how stale news from the base can be.

HOME's flavor query is one of those turns: 250 ms while lit and 500 ms while dark.
It carries main board flavor truth and durability to the machine display, including selections
that arrived from the faucet over J3. A selection on the machine display is an absolute, tokenized J9
request; main board revision publication carries the result to the faucet over full-duplex J3.

`link` on the main board console reports `desyncs`: collisions that reached the wire in spite of all that. On a healthy pair it stays at zero. Rising under load means the discipline is being violated somewhere, and the place to look is whatever recently learned to transmit.

## J3 is the faucet's direct UART

J3/SIG-6 is a separate full-duplex 3.3 V TTL link to the 1.47-inch faucet display. The
main board uses IO33 TX / IO35 RX; the faucet uses GPIO43 TX / GPIO44 RX, crossed TX to RX,
at 921600 baud — direct TTL, with no transceiver ceiling over it. TinyProto Fd supplies
framing, CRC, acknowledgements and keepalives. J3 has
independent TX and RX conductors, so none of J9's half-duplex turn-taking or echo cancellation
belongs on this link.

A faucet tap changes the local logo first, then queues `MSG_FLAVOR_SELECT` with an absolute
flavor and request token. The main board acknowledges its authoritative value and persists it
in NVS. Repeating a token cannot repeat the selection or its sound. At first installation only,
a main board with no stored flavor adopts the faucet's cached selection; every established
main board wins reconciliation. Both boards defer flash writes away from the touch path.

## What the links carry, measured

Both displays carry a WiFi radio no product path uses, and every image the
machine moves goes over the wires instead. `wifi` and `bench j3` on the main
board console are what that comparison is made of. All four numbers below are
one bench, one room, `RSSI -40 dBm`.

| Path | Rate | What is in it |
|---|---|---|
| J3, OTA pull | 9.2 KB/s | the shipping path: 1 KB asked for, waited on, written to flash |
| J9, OTA pull | 11.2 KB/s | the same, across the half-duplex pair |
| J3, `bench j3` | 71–74 KB/s | the wire itself — TinyProto's window, nothing written |
| WiFi, BLE advertising | 99–135 KB/s | faucet display to machine display, SoftAP and one TCP socket |
| WiFi, BLE off the air | 299–349 KB/s | the same run with `wifi <KB>q` |

**The pull is most of what the wired numbers are.** J3 runs at 921600 and
carries 82% of that when nothing is taking turns on it; the OTA path gets 12%
of the same wire. What the difference buys is a receiver that stores no more
than a frame — the property that lets a phone update four boards through a
main board holding one chunk — and it costs a round trip per kilobyte.

**The radio is one antenna and BLE is on it.** The faucet advertises to the
phone with the same PHY it would forward over, and coexistence takes about two
thirds of the throughput. A trailing `q` stops advertising for the length of a
run, which is what the two WiFi rows are.

**The machine display's radio and its panel cannot both be up.** Its scan-out DMA
refills a bounce buffer out of PSRAM and bringing WiFi up writes flash, which
suspends the cache PSRAM is reached through — the conflict that already blanks
this glass for an arriving image. `wifi on` takes the panel down the same way
an OTA does, and the board reboots when the run ends. The faucet drives SPI and
has no such conflict.

```
wifi on | off        raise or drop the machine display's bench AP
wifi <KB>[q]         the faucet joins it and sends; q takes BLE off the air
bench j3 [<KB>]      push at J3 as fast as its window will take frames
```

Both are refused unless the machine is dark: each holds the main board's loop
for the length of a run.

## A user's own pictures

Eight faces a channel can wear. The low four are the factory faces: they sit in the
image store's lower four slots, laid out by [`tools/make_logos.py`](/tools/make_logos.py)
and written by a firmware update (`OTA_KIND_LOGOS`), never by the owner, so a machine
whose owner deleted everything they added still has four. The high four are theirs,
and only ever arrive from a phone.

**The phone sends pixels, not photographs.** A picture crossing BLE is already
cropped, resampled and dithered to RGB565 at exactly the sizes each panel draws
— three renditions, `IMAGE_BUNDLE` in [`proto_msg.h`](lib/proto_link/proto_msg.h):
172x320, 129x240 and 86x160. Neither board decodes or scales anything; each is
handed a pointer into mapped flash and renders straight out of it, the way
`board_art` already renders the loading animation.

**One shape, at three scales.** Every rendition is 43:80 — the faucet's glass —
so a photograph gives the machine one rectangle and every surface that shows a
logo shows the same picture. The faucet fills its glass with the largest; the
machine display keeps the same bundle and caches complete portraits at its Big Blue rail,
selected-image and picker sizes. Both boards keep all three, so a
slot's own crc32 is its identity on either of them and the reconcile below has
one number to compare.

**Both stores live in the partition nothing was using.** `spiffs` — 9.94 MB on
the faucet, 6.94 MB on the machine display — needed no table change, which matters
because a partition table is the one thing an update cannot install. A slot
stands on its own erase boundary and carries its own header, written last, so a
transfer cut short costs that one picture and leaves the slot reading empty
rather than showing half a face.

**The faucet is the master copy.** It has the radio and the space, so it keeps
every rendition either glass draws — a machine display can be replaced and
re-provisioned from it with no phone in the room.

**Writing is the rare case and it is what costs.** Reading is a pointer, which
is why this is flash and not PSRAM: re-sending on every boot would trade a cost
paid once for a cost paid always. A picture chosen months ago is on both
glasses the instant they boot.

```
phone  ──BLE──▶  faucet display  ──WiFi──▶  machine display
                       │                             │
                       └── all three, byte for byte ──┘
```

The last hop is the radio rather than J9 because the machine display's panel has to
come down for a flash write either way — so the transport that costs nothing
extra at that moment is the fast one. A bundle is 199,520 bytes; measured at
**180 KB/s**, against the 15 s J9 would take. The access point stands only for
that burst and the board reboots into its new face when it drops.

```
images                 what each display holds
images test <slot>     have the faucet make itself a picture, with no phone
images relay <slot>    carry one to the machine display over the radio
```

## What the machine firmware must hold

Three constraints the main board and the supply impose, each carried by a part that pays for a violation. They are in [`firmware-and-commissioning.md`](/hardware/assembly/firmware-and-commissioning.md) §9 as well, where the factory confirms them per unit.

- **At most 3 solenoid valves energized at once.** Eight coils on MANIFOLD A draw 2.4–3.7 A through J1's `COM` contact, rated ~3 A, and dissipate it in one SOIC-18 (U4). The canonical valve states open at most three ([`/hardware/topology/fluid-topology.md`](/hardware/topology/fluid-topology.md)); the ceiling is [`/hardware/wiring/ac-wiring-schedule.md`](/hardware/wiring/ac-wiring-schedule.md) "Solenoid COM current budget".
- **Relay #1 (`IO19`) and the condenser fan follow the cold loop.** `lib/machine_policy/cold_policy.h` is the whole decision — the setpoint band on the carbonator wall, the freeze cutout on the suction line, the compressor's minimum off-time and the parking of both on a reading that is missing or stale. The condenser fan shares its write with every valve, so `machine.cpp` routes them all through one `applyOutputs()` and a valve change during a run does not stop the fan.
- **Relay #1 (`IO19`) and the condenser fan follow the cold loop.** [`lib/machine_policy/cold_policy.h`](lib/machine_policy/cold_policy.h) is the whole decision — the band on the carbonator wall, the freeze cutout on the suction line, the compressor's minimum off-time, and both parked on a reading that is missing or stale. The fan shares its write with every valve, so `machine.cpp` routes all of them through one `applyOutputs()`: a valve change during a compressor run does not stop the condenser.
- **Relay #2 (`IO2`) off while a dispense is open.** The main board peaks at 3.33 A and the G Ganen diaphragm pump is budgeted at 5 A on the same 12 V rail — 8.32 A together, against a 6.7 A supply. The carbonator's low reed asserts mid-pour, so the refill it queues waits for the dispense window to close ([`/hardware/assembly/acceptance-and-burn-in.md`](/hardware/assembly/acceptance-and-burn-in.md) step 5). Nothing in hardware enforces this. `machine_policy::kRefillDuringDispense` is the policy that refuses such a plan and `machineDispenseWindowOpen()` is the accessor that asks. [`lib/machine_policy/refill_policy.h`](lib/machine_policy/refill_policy.h) is the draw itself: CLO debounced, the ask held in `Queued` while the window is open, the latch to CHI, a ceiling on pumping time and a fault on two reeds that cannot both be closed. A pour beginning mid-draw stops the draw before it opens its own path.
- **`GPPU` written on both MCP23017s.** No loom carries a resistor and the main board pulls none of the reed inputs ([`pcba.tsx`](/hardware/pcb/pcba/pcba.tsx), U2 GPB4-7 / U3 GPB6-7), so every reed reads its expander's internal pull-up or floats.

`pio test -e native` holds these policies off-board: it checks the cold loop's band, its freeze
cutout and recovery, its minimum on- and off-times and every path out of a reading it cannot
believe; the refill's debounce, dispense interlock, latch, ceiling and fault; the canonical operation table,
all logical valve transitions, the complete physical expander map and fault parking, pump
deadline boundaries, the pour's duty shape, the echo matcher's resync, and the gas alarm's
exemption from every volume and quiet-hours setting the two can be in — without opening a
serial port. See [`test/README.md`](test/README.md).

## Displays

- **ESP32-S3 machine display** (Waveshare ESP32-S3-Touch-LCD-4.3B) — Big Blue on the machine's 800×480 touchscreen: a persistent 104 px flavor rail, 234 px selected portrait and 462 px task pane. Fill, Prime and Clean sit above the task; Settings opens the full 696 px area beside the rail. On tap carries the selected reservoir reading, with image and ratio editors one press away. The On tap faucet mark pulses during boot. Queued/running Fill, Clean and Dry expose only Stop until the main board confirms the operation ended. Prime uses the shared tokenized `MSG_PRIME_SESSION_*` protocol, with causal cancellation and stop retries. `src_front/` drives the RGB panel through esp_lcd with double framebuffers and bounce buffers; J9 on GPIO43/44 carries selection, operations, sensor state, image updates and OTA. See [`src_front/README.md`](src_front/README.md).

## The pour

Carbonated water flows at the faucet and the selected channel's pump injects concentrate into
it on a duty cycle that follows the flow. The DIGITEN meter's pulses are counted over 50 ms,
and each count is one reading:

| Flow reading | On | Off | Duty |
|---|---|---|---|
| 1 pulse / 50 ms | 50 ms | 600 ms | ~8% |
| 6 pulses / 50 ms | 200 ms | 300 ms | ~40% |

The channel's ratio scales that. 1:20 is the SodaStream-compatible bottle and is the shape
above; 1:6 is bag-in-box syrup, and at full flow the head stays on.
[`machine_policy::pourCycleTiming`](lib/machine_policy/pour_policy.h) is the whole of it, and
`pio test -e native` checks its boundaries and the phases either side.

## Pin Assignments

The main board's pin map is [`pcba.tsx`](/hardware/pcb/pcba/pcba.tsx), drawn as
[`/hardware/wiring/esp32-pinout.mmd`](/hardware/wiring/esp32-pinout.mmd); the 4.3B's is
[`src_front/README.md`](src_front/README.md). The faucet display's is below, fixed by the
board design.

### ESP32-S3 Faucet Display (Waveshare ESP32-S3-Touch-LCD-1.47)

All pins are fixed by the board design.

| Function | GPIO | Notes |
|---|---|---|
| LCD SPI MOSI | 39 | JD9853, 172x320 — ST7789 command set + panel init sequence |
| LCD SPI SCLK | 38 | |
| LCD CS | 21 | |
| LCD DC | 45 | |
| LCD RST | 40 | |
| LCD Backlight | 46 | |
| Touch SDA | 42 | AXS5106L, Wire I2C, addr 0x63 |
| Touch SCL | 41 | |
| Touch INT | 48 | FALLING edge per touch report |
| Touch RST | 47 | |
| J3 UART TX | 43 | 921600 baud, TinyProto Fd to main board IO35 RX |
| J3 UART RX | 44 | 921600 baud, TinyProto Fd from main board IO33 TX |
| BOOT button | 0 | |

## A shipped unit is updated from the iOS app

**The phone is the update path.** A customer's machine is never on WiFi and never on the
internet — the air gap is deliberate — so BLE from a phone standing in the kitchen is how new
firmware reaches a unit in the field. USB, below, is the bench path.

Four links, one pull. The receiver asks for the offset it is ready to write; whoever is upstream
of it asks the next one out; the phone answers. One chunk is in flight anywhere on the path and
no board between the phone and the flash stores more than a frame.

```
homesodamachine.com  ──HTTPS──▶  iOS app  ──BLE──▶  faucet display
                                                          │
                                                          J3
                                                          ▼
                               machine display  ◀──J9──  main board
```

**The faucet display carries the radio** ([`src_faucet/ble_link.cpp`](src_faucet/ble_link.cpp)):
NimBLE on the Nordic UART Service, at the end of the gooseneck, above the counter, in open air.
An image for the faucet goes from the phone into its own spare slot with no relay in it. Anything
else goes onto J3 as it lands, and [`src_appliance/ota.cpp`](src_appliance/ota.cpp) is the relay
that carries it the rest of the way. That relay takes its bytes from the console or from J3 —
`MSG_OTA_SRC_BEGIN` / `_NEED` / `_DATA` / `_END` in
[`proto_msg.h`](lib/proto_link/proto_msg.h) — and everything downstream of that question is one
path.

**What a machine advertises comes from its main board.** A display is one board out of a pair
that could be wired to either machine; the main board is the machine. `MSG_IDENTITY_QUERY`
answers with the model and the low three bytes of the main board's own MAC, and the faucet puts
that in its local name and in a `0xFFFF` manufacturer block. Two machines a metre apart are
distinguishable in a scan result, before either is connected to. `identity <name>` on the main
board console sets a name; so does BLE text `IDENTITY <name>` from the phone, which the display
with the radio carries to the main board as `MSG_IDENTITY_SET` and answers with the identity
frame once the main board has it. `ble` reports the radio the main board cannot see.

**Every phone in the house can reach it.** The faucet advertises whenever it has room for
another connection, at the stack's 30–60 ms with no phone on and every 400–500 ms beside one,
so a phone holding the link from a pocket does not hide the machine from the next. The frame
protocol has one phone in it at a time. The session is the link that last spoke with nothing in
flight: frames are sized to its MTU, and only its leaving ends a transfer. A reply goes back down
the link that asked, and anything else goes to every link that can carry it. The controller is
written both payloads again every ten seconds and restarted a second after it is found off air
with room, because nothing can read back what it holds. ESP's connection reattempt is compiled
out (`platformio.ini`): it restarts advertising from a field set NimBLE-Arduino never fills,
which leaves a connectable, empty advertisement that a phone filtering on the service never
sees. While its page is open, the app asks for the machine it knows by peripheral id as well
as listening for it, and lets the link go if the board answers with a different unit; it lets
the link go when it leaves the screen, unless an update or a picture is crossing it. While
another phone's transfer is in flight, a second phone's BEGIN is answered busy.

**What an update is, per board.** Firmware goes into the OTA slot that is not running and the
boot partition moves only after the whole image is in and its CRC32 matches; a transfer that
stalls leaves the board running what it booted. The machine display also carries `art` — a data
partition holding the loading animation, erased and rewritten in place, verified the same way.

| Target | Image | Slot | Reached over |
|---|---|---|---|
| `self` | `appliance` | 768 KB | J3, or the console |
| `faucet` | `esp32s3_faucet` | 3 MB | BLE, or J3 from the console |
| `enclosure` | `esp32s3_front` | 2.5 MB | J9 |
| `art` | `tools/make_art.py enclosure` | 4 MB | J9 |

**The machine display goes dark while it writes.** Its scan-out DMA refills a bounce buffer
from PSRAM, a flash write suspends the cache PSRAM is reached through, and the refill then
faults — the same constraint that keeps its logo choice on the main board rather than in local
NVS. So it says what is about to happen, stops the panel, takes the image dark and reboots either
way. A failed transfer costs a reboot into the image it was already running, and so does one
that simply stops: the glass is dark until it reboots, the abort that ends a transfer is only
ever sent by a relay session that still exists, and a minute with no bytes is a minute nothing
upstream is coming back from. The faucet drives SPI, has no such conflict, and shows a live
percentage.

### Where the images come from

[`tools/publish_firmware.py`](/tools/publish_firmware.py) builds every image, packs one
content-addressed release asset and points main at it in
[`firmware/firmware-images.json`](firmware-images.json) — each image by target, `FW_VERSION`, size,
the crc32 `MSG_OTA_BEGIN` promises, and a sha256. `web/scripts/fetch-firmware.mjs` puts the bytes
on the deploy's disk and `/api/firmware` serves the manifest; `render.yaml` names the pointer file in its
build filter, so publishing firmware deploys the site the way a geometry publish does.

The version string is the board's own: `pre_build.py` writes `FW_VERSION` into each tree from
HEAD's date and short SHA, the board reports that string, and the manifest carries the same one.

**What a person reads and what the phone compares are two fields.** A date is as fine as a
string a screen has room for, and two builds made on one day are not ordered by one — so
`pre_build.py` stamps `FW_BUILD_EPOCH` beside it, HEAD's commit time, and that is the only
field an update is decided by. It travels in `VersionPayload` and in the manifest, leaving the
string free to stay readable. Which of two builds is newer is the question that has to be right:
the phone is the only place a machine can be refused its own past, because the receiver holds the
image to its crc32 and moves its boot partition without asking what it came from. Where either
end predates the field it reads as "did not say", and the dates in the strings answer instead —
which cannot separate two builds made on one day, so neither is offered over the other.

```bash
~/.platformio/penv/bin/python tools/publish_firmware.py --write
```

## The bench path

`tools/ota.py` pushes through the main board's USB console — the same relay, with the console as
the source instead of J3:

```bash
~/.platformio/penv/bin/python tools/ota.py enclosure
```

Targets are `self`, `faucet`, `enclosure` and `art`; `pio run -e <env>` first. The console runs
at 500000 for the duration of a session and drops back when it ends.

`tools/boards.py` names each S3 on sight — every one reports its MAC as its USB serial number.

## The bench, from the shell

The boards and the camera on this Mac's USB are run and watched from the shell, with no hand on
the glass.

- **The main board's console** — `status`, `pump <a|b> [ms]`, `ui <page> [a|b] [go]`, `test`,
  `wake`, `selftest` and the rest — is in [`src_appliance/README.md`](src_appliance/README.md).
  Opening its CH340 port restarts the board; [`tools/panelcam-console.py`](/tools/panelcam-console.py)
  waits out the restart and sends one line.
- **The machine display's own console**, on its native USB, runs the pads' handlers without a
  finger: `PRIME:START:<1|2>` / `PRIME:STOP`, `FILL:START:<1|2>`, `CLEAN:START:<1|2>`, `AIR:DRY`
  ([`src_front/README.md`](src_front/README.md)). [`tools/firmware_live_check.py`](/tools/firmware_live_check.py)
  runs the live checks through that port and never opens the main board's; `--prime a|b` holds
  Prime for one second. [`tools/firmware_faucet_check.py`](/tools/firmware_faucet_check.py)
  checks the faucet display through its own native USB and drives nothing
  ([`test/README.md`](test/README.md)).
- **The camera** is [`tools/panelcam.sh`](/tools/panelcam.sh): `shot front` photographs the
  machine display onto its own 800×480 grid, and `aim front` refits the corners after the rig
  moves. The frame is taken by `tools/panelcam-shot/PanelCamShot.app`, which holds the camera
  permission; a shell cannot open the camera.

## Building and Flashing

Every environment in [`/platformio.ini`](/platformio.ini) builds with `pio run -e <env>` and
flashes with `-t upload`. `firmware/pre_build.py` runs first on the four that report a build
ID, stamping `fw_version.h` from the git rev so a board says which commit it was built from.
`weld_rotator` names no pre-build script and reports none.

**With more than one board on USB, name the port.** PlatformIO picks one otherwise, and it picks the S3 — esptool opens that port, drops the display into download mode, and only then fails on the chip id, leaving the panel dark until it is reflashed ([`/hardware/pcb/pcba/bench-log.md`](/hardware/pcb/pcba/bench-log.md)).

[`tools/boards.py`](/tools/boards.py) says which board is on which port and prints the commands with the ports already filled in. It only enumerates — it never opens a port, because opening one drives the main board's Q2/Q3 auto-reset lattice and reboots it.

```bash
~/.platformio/penv/bin/python tools/boards.py
```

**An externally-powered machine display can explicitly reattach to USB without cycling the machine.** J9 is `[B, A, GND, V12]`, and `J9.V12` runs straight to the V12 island with no relay, so firmware cannot drop display power. Instead, the development command below asks a running display to put its USB Serial/JTAG PHY into deep sleep for 500 ms; timer wake then presents a real USB detach/attach.

```bash
~/.platformio/penv/bin/python tools/display_usb.py
```

The command is explicit development control and is never sent by a production boot path. It finishes by observing the old USB attachment disappear, opening the re-enumerated display and requiring a `VERSION:ENCLOSURE=...` reply. If it reports `UNREACHABLE`, the installed display image is too old or the display is not answering on J9; that one boot still needs the physical RESET button or a V12 power cycle before the current image can be flashed.

```bash
PLATFORMIO_UPLOAD_PORT=/dev/cu.usbserial-10 pio run -e appliance -t upload
```

### Flash the machine controller

```bash
pio run -e appliance -t upload
```

See [`src_appliance/README.md`](src_appliance/README.md) for its console.

### Flash the main board's bring-up console instead

```bash
pio run -e pcba_bench -t upload
```

For a bare main board on the bench, not an assembled machine. See [`src_pcba_bench/README.md`](src_pcba_bench/README.md) for its command table.

Both go over a plain USB-C cable into J14; the on-board CH340B bridges and Q2/Q3 auto-reset, so no button presses.

### Flash the machine display's art partition

The loading animation is not in that board's firmware image — it is 3.96 MB in
the `art` partition, built from the same `src_front/images/anim_NN.h` headers by
[`tools/make_art.py`](/tools/make_art.py), which `pre_build.py` runs
for this environment. `esp_partition_mmap` hands LVGL a pointer into it, so it
renders straight out of flash at no RAM cost, exactly as compiled-in `.rodata`
did — it just stops riding along in every update of code that never touches it.

A board whose `art` partition is empty runs and shows its pointer file screen without a
logo; `ART` on its console says what is there and `ART:VERIFY` walks the CRC.

```bash
PLATFORMIO_UPLOAD_PORT=/dev/cu.usbmodem1101 ~/.platformio/penv/bin/python -m esptool --chip esp32s3 write-flash 0x510000 .pio/build/esp32s3_front/art.bin
```

Over the link instead, with only the main board on USB:

```bash
~/.platformio/penv/bin/python tools/ota.py art
```

### Flash the ESP32-S3 (4.3B machine display)

```bash
pio run -e esp32s3_front -t upload
```

### Flash the ESP32-S3 (faucet display)

```bash
pio run -e esp32s3_faucet -t upload
```

The [pioarduino platform](https://github.com/pioarduino/platform-espressif32) for Arduino core 3.x, and [LVGL v8.4](https://github.com/lvgl/lvgl) for the UI. The JD9853 panel is driven through the GFX library's ST7789 driver plus a panel-specific init sequence; the AXS5106L touch driver lives in `src_faucet/axs5106l.cpp`. Rotation 0 puts the USB connector down on the faucet mount. Test commands over USB serial (115200 baud): `GET_STATE`, `TOGGLE`, `FLAVOR:n`, `GET_DIAG`, `BL:n` (raw backlight duty), `GET_VERSION`.

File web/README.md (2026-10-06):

# web/

The Node web server for **homesodamachine.com** + the browser-rendered viewer at `/3d` and `/charts`. No bundler. Runs on Render as a single web service, plus a Postgres add-on for the notification inbox and FCM hash tables. The dev story is the same code with a chokidar wrapper.

The hardware/firmware/CAD content the site presents lives in [`hardware/`](/hardware/) at the repo root — that side is its own world (CadQuery, KiCad, ESP-IDF). This document covers the web layer only.

## Running it

```bash
cd web
npm ci             # installs package-lock.json exactly — what Render runs
npm start          # production server (port 3001 by default; PORT env overrides)
npm run dev        # dev wrapper: chokidar + Python runner + WebSocket hot reload (port 3000)
npm run dev -- --no-watch  # same server, no watchers: nothing rebuilds on save
npm test           # route mount, walkers, contracts — no browser, no DB
npm run test:browser # the browser pass (tests/browser/), on demand
npm run build      # rebuild every CAD generator + PCB board, producers first (minutes)
npm run build:check # same, then exit 1 if a rebuild moved anything — the fix is left in the tree
npm run subscribers # the signup list; DATABASE_URL comes from Render's dashboard
```

`npm start` boots `server.js` directly — what Render runs in production. `npm run dev` adds the file watcher that re-runs CadQuery generator scripts when a CAD source changes and pushes file-change events over the WebSocket so an open `/3d` page hot-reloads its thumbnails. A "generator" is any part-named `.py` under `hardware/` that calls `export_step` / `export_assembly` / `export_dxf` from `_cadq_export`; the watcher detects them by content, not filename. `--no-watch` serves the same site with no chokidar at all — no generator runs, no board renders, no thumbnails, no hot-reload broadcast — so an edit anywhere in the tree costs nothing and the viewer shows what is on disk until you reload it. Set `DATABASE_URL` to enable the notification inbox + FCM push paths; both no-op without a DB so dev works fine without one.

## Dependencies

`package-lock.json` is tracked, and is what the deployed site installs. `render.yaml` installs it with `npm ci --omit=dev`, which resolves nothing and stops when the lockfile and `package.json` disagree.

`overrides` pins `uuid` to `^11.1.1`. Below that it misses a buffer bounds check in its v3/v5/v6 generators. It arrives four levels down — `firebase-admin` → `@google-cloud/storage` → `retry-request`/`teeny-request` → `uuid` — and again through `gaxios`.

Node 22 is the floor, in `engines` and in `.node-version`: `firebase-admin` 14 declares `>=22`, and Render reads `.node-version` from the service's root directory. `npm run audit` reads the production half of the tree.

## Page request lifecycle

```
HTTP GET /<path>
   │
   ▼
server.js  ── start({ dev }) ──┬─ pg.Pool from DATABASE_URL (null if missing)
   │                            ├─ initPush(serviceAccountJson)
   │                            └─ for each lib/<name>.js:
   │                                  mountXxxRoutes(app, …)        // attaches GET handlers
   │
   ▼  (route handler in lib/<name>.js)
res.send(
  renderHead({…})          // <head>: meta, fonts, /css/site.css, HEAD_TAGS, page styles
  + renderNav({active})
  + <body fragment>        // either inline HTML or a template fragment from lib/templates/
  + renderFooter()
)

Browser receives HTML. Inline pre-paint <script> sets the notifs-enabled
class from localStorage. Then deferred /boot.js runs (SW bridge, notifications
state, WebSocket owner, /api/version activation check). Then any page-specific
module (/landing.js, /js/viewer/main.js, etc.).
```

The single shared shell is [`lib/shell.js`](/web/lib/shell.js). Every page uses `renderHead` and `renderFooter`. Public and engineering pages use `renderNav`, which draws the same icons everywhere: Home, Updates, Parts, Charts, Drawings, Boards and Cost, then the bell and the gear. Unit pages have their own named navigation: Your machine, Get started, and Guides.

## Module layout

### `lib/` — server-side

| Module | Mounts | Responsibility |
|---|---|---|
| [`server.js`](/web/server.js) | `/api/version` | Entry; orchestrates the pool, push init, route mounts, WebSocket broadcast diff loop on prod boot. Serves the live build commit at `/api/version` for boot.js's activation check. |
| [`lib/shell.js`](/web/lib/shell.js) | — | `renderHead` / `renderNav` / `renderFooter`. Owns the synchronous pre-paint class flips and the `<script src="/boot.js" defer>` tag. |
| [`lib/landing.js`](/web/lib/landing.js) | `/` | Marketing landing + email signup form. |
| [`lib/unit.js`](/web/lib/unit.js) | `/0001`, `/0001/get-started`, `/0001/guides` | Machine overview, included equipment, preparation checklist, and owner documents. Only serials registered in this module resolve. |
| [`lib/cost.js`](/web/lib/cost.js) | `/cost` | Parts, planned batch labor, sale price, investment recovery and remaining-purchase forecasts for the first 5/10/20 machines. Reads the parts, labor, machine-time, purchase and batch-forecast ledgers. [`lib/batch-forecast.js`](/web/lib/batch-forecast.js) deducts dated stock and already-ordered quantities before comparing whole purchase lots. [`lib/batch-forecast-view.js`](/web/lib/batch-forecast-view.js) renders ranked purchase bars and collapsible stock, supply and cash-budget details; [`lib/cost-categories.js`](/web/lib/cost-categories.js) shares the BOM category names between both cost views. |
| [`lib/viewer-pages.js`](/web/lib/viewer-pages.js) | `/3d`, `/charts`, `/drawings`, `/pcb` | The viewer pages — parts, charts, the documents shelf, boards. All render [`lib/templates/viewer-body.html`](/web/lib/templates/viewer-body.html). |
| [`lib/weld-position.js`](/web/lib/weld-position.js) | `/weld-position` | Tube, recessed endcap and gun orientation; grip, hole and vertical rotations about the laser dot. |
| [`lib/viewer-routes.js`](/web/lib/viewer-routes.js) | `/api/{steps,dxf,mermaid,documents}`, `/steps/*`, `/dxfs/*`, `/read/*`, `/docs/*`, `/api/mermaid-content/*` | API for the viewer's file lists and content, plus document publication gates. |
| [`lib/document-reader.js`](/web/lib/document-reader.js) | `/vendor/pdfjs/<version>/*` | Document reader HTML and the installed PDF.js assets. `/read/*` renders one page at a time through `public/document-reader.js`, with page links, history, selectable text and zoom. `/docs/*?raw=1` supplies range-capable PDF bytes; `?download=1` supplies an attachment. HTML navigations to saved `/docs/*` links redirect to the reader. |
| [`lib/settings.js`](/web/lib/settings.js) | `/settings` | Per-user toggles: FCM enable, live-reload debug. |
| [`lib/events.js`](/web/lib/events.js) | `/ws` | WebSocket channel. One socket per page: deploy hello-handshake + ping heartbeat + `files-changed` broadcasts. |
| [`lib/notifications.js`](/web/lib/notifications.js) | `/api/notifications/*`, `/notifications` | Per-token inbox CRUD + the `/notifications` page. |
| [`lib/push.js`](/web/lib/push.js) | `/api/push/*` | FCM subscriptions + outbound notify; boot-time hash diff against per-kind tables. |
| [`lib/walk.js`](/web/lib/walk.js) | — | Shared `walkFiles(rootDir, exts)` helper, plus the per-kind walkers (`walkPcbBoards`, `walkDocuments`). |
| [`lib/icons.js`](/web/lib/icons.js) | — | Shared SVG glyphs (cube, chart, gear, bell, scissors, clipboard). |

The pattern: `export function mountXxxRoutes(app, { … } = {})`. `server.js` calls each in sequence. To add a new page or API surface, add `lib/foo.js` with `mountFooRoutes`, import and call it from `server.js`.

### `public/` — browser-side

Served flat via `express.static(public/)`.

| File | Loaded on | Role |
|---|---|---|
| [`public/boot.js`](/web/public/boot.js) | every page (`<script defer>`) | SW navigate bridge, notifications state mirror + bell + toast + warm-tap auto-redirect, WebSocket owner, `/api/version` deploy/activation check (reloads the page on a new build unless the viewer claims it via `window.__hsmDeploySoft`). Module-local state — never touches `window.__hsm`. |
| [`public/landing.js`](/web/public/landing.js) | `/` | Signup form submit and feedback. |
| [`public/cost.js`](/web/public/cost.js) | `/cost` | Cost overview navigation and sales scenario controls. Three accordion cards show per-unit cost, investment recovery and the 5/10/20 forecast in that order, with headline totals visible while collapsed. Jump links and direct section links reveal the relevant card; recovery controls update its summary. `cost-recovery.js` shares recovery math and the SVG chart with the server. `batch-forecast.js` selects the 5/10/20 plan, defaults to Parts category, and filters suppliers and stock-covered parts. Compact purchase lists scroll; each item expands for source, lots and stock evidence. The overview, category grouping and all three batch disclosures work without JavaScript. |
| [`public/unit.js`](/web/public/unit.js) | Unit pages | Opens the included-equipment disclosure from its link and saves preparation checkmarks in this browser, keyed by serial. Navigation and documents are server-rendered links. |
| [`public/settings.js`](/web/public/settings.js) | `/settings` | Notification + live-reload debug toggles. |
| [`public/brand/mark.svg`](/web/public/brand/mark.svg) | every page | The faucet mark in the Home link and landing hero. Generated from [`../brand/mark.svg`](../brand/mark.svg) by [`../tools/build_brand_assets.py`](../tools/build_brand_assets.py). |
| [`public/pan-zoom.js`](/web/public/pan-zoom.js) | `/3d`, `/charts` | Generic pan + pinch-zoom + wheel-zoom. |
| [`public/content-viewer.js`](/web/public/content-viewer.js) | `/3d`, `/charts` | Modal singleton: open / close / swipe-down / Esc / X / backdrop. |
| `public/js/viewer/*.js` | `/3d`, `/charts` | The parts/charts viewer modules — see below. |
| `public/css/viewer.css` | `/3d`, `/charts` | Viewer-specific styles. |

### `public/js/viewer/` — the parts viewer modules

`/3d` and `/charts` share one module graph (the entry decides what to show based on `location.pathname`). Each module is a browser-native ES module loaded via the importmap in [`lib/templates/viewer-body.html`](/web/lib/templates/viewer-body.html).

| Module | Role |
|---|---|
| `state.js` | Single exported `state` object holding all shared mutable refs (`allFiles`, `currentDetail`, `mountedDetail`, caches, etag maps, `gridEl`). Every other module reads/writes through `state.X`. |
| `scene.js` | Three.js renderer/camera/controls/scene/lighting + ViewCube + animate loop + per-file camera persistence + canvas reparenting (canvases live in `#cad-canvas-host` between opens). |
| `step.js` | STEP loader (occt-import-js), parser, mesher, thumbnail renderer. |
| `faucet-options.js` | The faucet's Sculpted/Industrial style and Black/White finish controls. Style swaps actual assembly payloads in the same view; finish recolors the printed exterior, lever, above-counter gasket, soda faucet tube and the flavor pair's runs through the faucet, including their direct part views, and shows a White faucet's two flavor unions or a Black faucet's bridges in their place, with no payload change. Fresh faucet views are solid unless the browser holds an explicit x-ray preference. On narrow screens the choices expand from a compact summary. |
| `dxf.js` | DXF loader, parser and extrusion mesher. No page draws a card for a cut, so a `.dxf` is reached by opening it. |
| `mermaid.js` | Mermaid renderer (lazy-loaded library), thumbnail renderer, modal detail flow with PanZoom. |
| `cad-detail.js` | Shared modal flow for STEP+DXF (`openCadDetail`/`closeCadDetail`); the `CAD_KINDS` table maps type → ext/hashPrefix/loader. |
| `grid.js` | Card grid per page, `IntersectionObserver` for thumbnail lazy-load. `/3d` hands off to `parts.js`; charts and line art group by a path segment (`categoryAndPartPath`, `groupFilesByCategory`). |
| `parts.js` | `/3d`'s page: the machine's two units as one card each, seated by [`contracts/parts-tree.js`](/web/contracts/parts-tree.js). A card draws the model it opens, at the card's own size. Everything else — the cold core included — is reached by selecting its solid inside the assembly that holds it, which opens that file with the trail back. |
| `live.js` | WebSocket-driven refresh — `hsm:files-changed` listener + `refreshXxxCard` per type for per-file updates; `hsm:deploy` listener that wipes caches and refreshes the whole grid + open modal on a new build. Sets `window.__hsmDeploySoft`. |
| `route.js` | popstate + initial-route translation between URL hash/`?file=` and `currentDetail`. |
| `main.js` | Entry. Sets up nav active class + title, calls `fetchFiles`, applies the initial route. |

State sharing pattern is **one shared object** (`state.js`'s exported `state`). Other modules `import { state } from './state.js'` and read/write `state.allFiles` etc. directly. Live binding via the object identity; no per-module proxy or sync ceremony.

The Puppeteer escape hatch `window.__hsm` is set from `main.js` after all modules have loaded; its shape is part of the contract with [`tools/render/render-step*.js`](/tools/render/) (which lives at the repo root and imports `web/server.js`) and must not change without updating those.

## Unit pages

`/0001` presents the soda machine, faucet, and install kit. Its Get started page links the
seven installation steps to the matching pages of the install guide; Guides opens the quick
start, full booklet, and care pages. The cobalt layout is in `public/css/unit.css`. The common
head supplies boot behavior, icons, and metadata, with IBM Plex Sans and the unit page's theme
color. The pages work without JavaScript; the disclosure's direct link and saved checkmarks
are progressive enhancements.

`public/unit/faucet.webp` is the optimized copy of the install guide's committed
`hardware/install-guide/assets/steps/pour-base.png`. Regenerate it with
`node web/scripts/build-unit-assets.mjs`, using the Sharp dependency in `tools/render/`.

## Tube shape review

Open **Soda machine** at `/3d`, then turn on **Tubes** in the Show tools. Choose an
LLDPE run and use **Show run** to frame it. The cyan dashed line is the CAD route; the coloured
line is an assumed relaxed shape. Fitting exits and actual ties are marked. **Temporarily omit
a hold** recalculates the shape without that restraint; **Reset assumptions** restores every
hold. Selecting a hold, unsupported span or reported contact focuses that location.

The calculation keeps the exposed developed length, fitting exit directions and finite anchor
seats. CAD corner points are free to move. The stock can be assumed straight or curved in either
sense of a selected coil plane, with an adjustable assumed radius. These choices are scenarios,
not measured material memory or bounds on the installed shape. The unloaded, uniform-stiffness
centreline model minimizes bending energy subject to length constraints; it does not model
gravity, pressure, friction, torsion or the stiffness added by insulation. Convergence describes
a local numerical solution. A tightened tie fixes its place along the tube; axial slip through
the tie is not modeled. The stock's bend floor is a reported diagnostic, not an enforced
material law. An unfinished solve remains visibly marked and cannot establish an anchor need.

Capsules around each candidate centreline are screened against the displayed assembly's triangle
surfaces, including hidden parts and other tubes. Sleeves contribute their radius only along
their recorded lengths. The selected tube's own CAD body and co-moving sleeves are excluded;
fitting and anchor contacts are exempted only over their recorded interface intervals. The panel
compares contacts with the CAD route and identifies new locations. Contact is reported, not
resolved: a candidate passing through a part is not a feasible installed shape. Surface screening
does not detect self-contact or a span wholly enclosed inside a solid.

`tube-overlay-host.js` mounts the optional tool; `tube-overlay.js` owns its controls and scene
sibling. The canonical CAD group and its pick geometry are unchanged. A module worker runs
`tube-relaxation.js` and `tube-contacts.js`; mesh bounds and triangle trees are reused between
assumptions. The worker is created on demand and stopped when the tool closes.

The route sidecar is `public/tube-routes.json`, generated by
`hardware/scripts/tube_routes.py` with the CadQuery venv. `/api/tube-routes/manifold-layout/enclosure-assembly.step`
checks the assembly STEP, complete viewer payload and routing input digests before returning it.
The panel refuses stale data. Opening the tool never starts a CAD build.
The current run and hold readings are in
[`hardware/manifold-layout/tube-shapes.md`](/hardware/manifold-layout/tube-shapes.md).

## Cross-module event flow

```
WS  /ws  ─────────────► boot.js                ────► CustomEvent("hsm:files-changed", {files})
                          │                          ────► CustomEvent("hsm:deploy", {commitChanged})
                          ▼                          │
                     fetchNotifications()           │
                          │                          │
focus/visibility/pageshow │                          ▼
   ├─► fetchNotifications()│                     viewer/live.js  → __hsmDeploySoft set: refresh
   └─► GET /api/version ───┘                     grid + open modal in place
        (commit changed? ──► hsm:deploy)         other pages → boot.js reloads on hsm:deploy

FCM  → service worker → notification banner
       (tap → on iOS PWA, page focus → boot.js refetch → maybe redirect; on
        Android/Chrome desktop, SW posts {type:"navigate"} which boot.js handles)
```

Three signals drive the page: the WebSocket push, FCM, and activation (focus/visibility/pageshow). Activation does double duty — it refetches notifications AND polls `/api/version`, so a deploy that the socket missed (suspended PWA, lost `recent` race) still reloads the page the next time it's foregrounded. The notification signals all converge on `fetchNotifications()`, which keeps the local state mirror current and dispatches `hsm:notifications-updated` for the toast + bell.

## Dev vs prod

There is **one server core** ([`server.js`](/web/server.js)). The dev wrapper ([`dev-server/server.js`](/web/dev-server/server.js)) imports `start({ dev: true })` and *adds*:

- chokidar watcher on the repo's `hardware/` to re-run CadQuery generator scripts and broadcast `files-changed` over the `/ws` WebSocket.
- `findScriptsImportingStep` heuristic to also rebuild dependent scripts when a STEP they import changes.
- A Python runner that picks up any new part-named generator script (detected by `export_step` / `export_assembly` / `export_dxf` calls) automatically.

`dev: true` only changes two things in `server.js` itself: the `commit` signal — sent in the WebSocket hello and served at `/api/version` — becomes `"dev"` instead of the deploy SHA, and the boot-time push diff is skipped. Routes are identical.

To verify dev/prod parity, the test in `tests/smoke.test.js` boots `start({ dev: false })` against an ephemeral port. If module evaluation or any default route 5xx's, it fails before any UI test runs.

## Where things go (cheat sheet)

| You want to… | Touch |
|---|---|
| Add a new page at `/foo` | `lib/foo.js` (new) with `mountFooRoutes`, `import + mountFooRoutes(app)` in `server.js`. Add to `tests/smoke.test.js`. |
| Add per-page client JS | `public/foo.js`, link from `lib/foo.js`'s body via `<script src="/foo.js" defer>`. |
| Change something on the viewer | The relevant `public/js/viewer/<module>.js`. Don't put viewer-only things in `public/boot.js` — that loads on every page. |
| Add a new feather glyph | `lib/icons.js`, then import and use in the consumer. Don't inline SVG strings elsewhere. |
| Walk a directory by extension | `import { walkFiles } from "./walk.js"` (server-side). |
| Open a CAD detail modal | `openDetail(file)`, `openDxfDetail(file)` or `openGlbDetail(file)` from `cad-detail.js` — one name per kind, which is what `route.js`'s `OPENERS` tables. They are the whole of `openCadDetail(type, …)`; don't write a parallel modal flow. |
| Persist some viewer state across opens | Add to `state.js`'s exported `state` object. Don't introduce a fresh module-scope `let`. |
| Add a live event type | Define on the server in `lib/events.js` + `lib/push.js`, dispatch on the client in `public/boot.js`'s WebSocket message handler. Page modules listen via `window.addEventListener("hsm:foo")`. |
| Wake a user via FCM | `notifyFilesChanged` in `lib/push.js`. The boot-time diff in `server.js` shows the canonical wiring. |

## Things that are NOT here

- No bundler (esbuild/webpack/vite). Browser ES modules + the importmap in `lib/templates/viewer-body.html` is the whole story. If you reach for a bundler, ask why first — most "needs a bundler" arguments here are for problems we don't have.
- No framework (React/Vue/Svelte). The viewer uses Three.js + plain DOM; the rest is server-rendered HTML + small client modules.
- No auth, no sessions, no user accounts. The app identifies a user by their FCM token (when they enable notifications). Settings live in `localStorage`.
- No browser in `npm test`. The suite holds what stays still — the server boots, the public route surface answers, the walkers and the contracts agree. `npm run test:browser` is the browser pass, on demand. What the viewer renders moves with the hardware: which assemblies exist, which parts fill a branch, what a readout chip reads. If you reach for an assertion on one of those, ask why first.

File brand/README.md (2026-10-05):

# Home Soda Machine identity

The mark is a pale-blue faucet with a semicircular gooseneck, a rectangular foot,
a square-cut outlet and a circular orange drop. The app icon places it on cobalt.

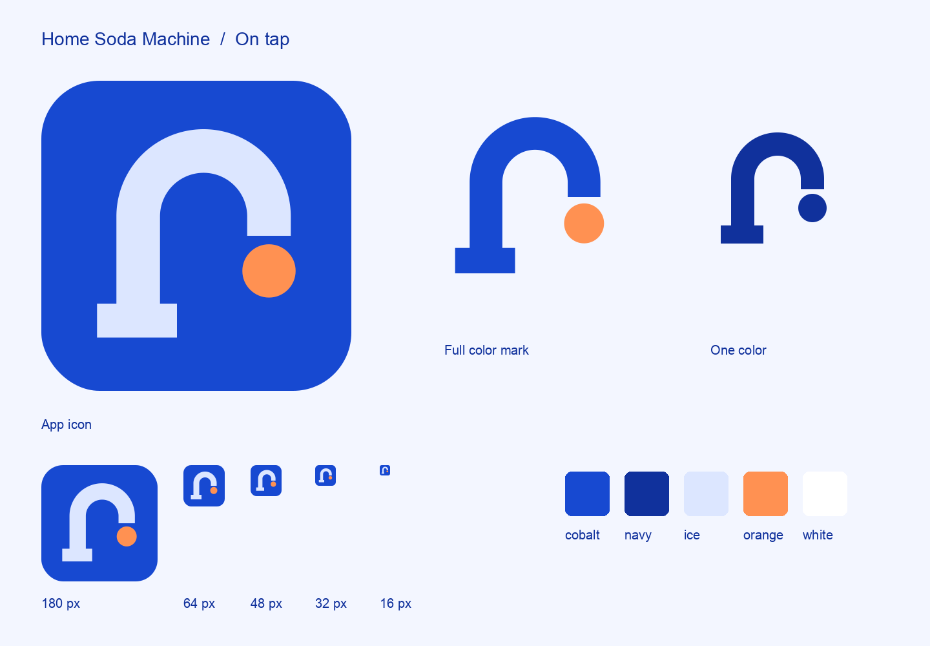
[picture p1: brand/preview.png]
Home Soda Machine identity


## Source and palette

[`mark.svg`](mark.svg) is the master geometry, in a 1024 × 1024 viewBox.
[`palette.json`](palette.json) holds the Big Blue colors.
[`wordmark-lettering.svg`](wordmark-lettering.svg) holds the outlined lettering.

| Color | Value | Use |
| --- | --- | --- |
| Cobalt | `#1749D1` | App icon and primary surfaces |
| Navy | `#10319C` | Text and recessed surfaces |
| Ice | `#DCE6FF` | Faucet and foreground on cobalt |
| Orange | `#FF9152` | Drop and primary action |
| White | `#FFFFFF` | Light surfaces and reverse artwork |

## Artwork

Production exports live in [`web/public/brand`](../web/public/brand/).

| File | Treatment |
| --- | --- |
| [`mark.svg`](../web/public/brand/mark.svg) | Transparent ice-blue faucet and orange drop |
| [`mark-blue.svg`](../web/public/brand/mark-blue.svg) | Cobalt faucet and orange drop for light surfaces |
| [`mark-mono.svg`](../web/public/brand/mark-mono.svg) | One color, inherited through SVG `currentColor` |
| [`mark-white.svg`](../web/public/brand/mark-white.svg) | White mark for dark surfaces |
| [`icon.svg`](../web/public/brand/icon.svg) | Rounded cobalt app icon |
| [`icon-square.svg`](../web/public/brand/icon-square.svg) | Full-bleed square icon for platform masks |
| [`avatar-1024.png`](../web/public/brand/avatar-1024.png) | Full-bleed cobalt square, the mark inside its inscribed circle, for round profile pictures |
| [`wordmark.svg`](../web/public/brand/wordmark.svg) | Horizontal mark and two-line name |
| [`wordmark-stacked.svg`](../web/public/brand/wordmark-stacked.svg) | Centered mark above the name |
| [`wordmark-reverse.svg`](../web/public/brand/wordmark-reverse.svg) | Light horizontal wordmark for cobalt surfaces |
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

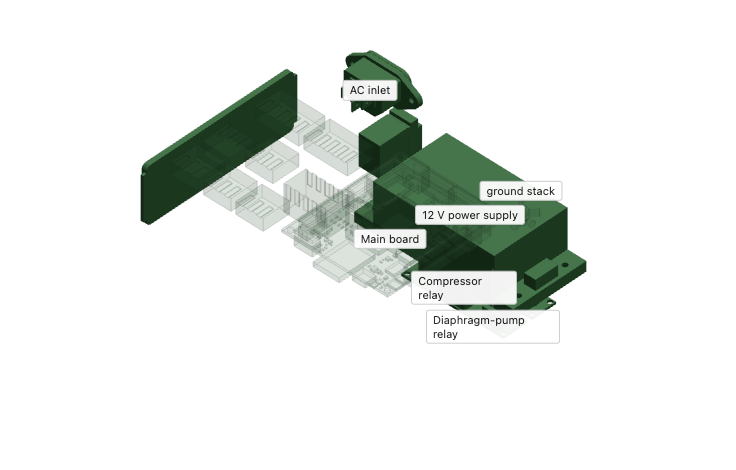
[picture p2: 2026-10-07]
future/pump-first-layout-study/renders/gallery/electronics-light-large.png

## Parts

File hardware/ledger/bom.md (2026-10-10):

# Bill of Materials — One Consumer Unit

Per-unit parts for a single finished appliance built on the **custom-carbonator** path specified in [hardware/README.md](/hardware/README.md). Carbonator: vertical 5" OD × 0.065" wall 316 welded SS round tube (OnlineMetals #12498, MTRs required) capped with 1/4"-thick laser-cut 316 SS circular plates from SendCutSend (`endcap-circular-2hole.dxf`), joined with the XLaserlab X1 Pro handheld laser welder. 1/4" NPT is direct-tapped into the plates (no weld-in bungs). Compressor is harvested from a countertop ice-maker; cold core is a 3D-printed foam shell with pour-in-place foam. Flavor reservoirs are custom printed translucent-PETG hard reservoirs ([printed-parts/cold-core/reservoir/reservoir.py](/hardware/printed-parts/cold-core/reservoir/reservoir.py)), two per build.

Tools, fabrication equipment (welder, slip roll, shop press, dishing dies), and duplicate SKUs live in [purchases.md](/hardware/ledger/purchases.md) only. Per-build consumables — anything used up making one unit, regardless of whether it ships in the product (mixing cups, gloves, citric acid, PTFE tape, cutting fluid, etc.) — live in this file with the rest of the per-unit parts.

First-pass draft. **Pricing convention: delivered cost** (product + shipping + tax) drawn from resolved order history in [purchases.md](/hardware/ledger/purchases.md) wherever the SKU has been ordered or acquired; list price for forward-plan SKUs not yet purchased. Pack-amortized lines show the math in the description (e.g., `$31.08/2`). Expect revisions.

## 1. Controllers + electronics

All controller, driver, and logic-rail electronics arrive pre-assembled on the JLCPCB-built main board ([`pcb/pcba/`](/hardware/pcb/pcba/)) — so it is **one delivered part** at the per-board price below, not a bag of components. The full on-board inventory (every LCSC part, per-part cost, designated second-sources) is the main board's own BOM: [`pcb/pcba/jlcpcb-parts.md`](/hardware/pcb/pcba/jlcpcb-parts.md) + the machine-generated `pcb/pcba/out/pcba.bom.csv`. Only the electronics that mount and wire **off** the main board get their own rows here — both displays, the PSU, and the DS3231's coin cell; the relays + MQ-6 live in §5.

| Part | Notes | Qty | Unit $ | Line $ |
|---|---|---:|---:|---:|
| Main board — JLCPCB-assembled, delivered ([order.md](/hardware/pcb/pcba/order.md)) | The populated controller board, ordered from JLCPCB as one assembled part — not a bag of components. On it: the bare ESP32-WROOM-32E, both MCP23017 GPIO expanders, the DS3231 RTC, both TBD62083 solenoid/fan sink drivers, both DRV8870 pump H-bridges, the RS485 transceiver, the on-board 5 V buck + 3.3 V LDO rails, the firmware-independent gas→compressor interlock (fed by the MQ-6 gas-sensor output divider), the MLT-5020 buzzer, the USB-C programming block, the reverse-polarity-protected 12 V inlet, and every field connector J1–J14. 4-layer 85 × 72.8 mm, ENIG, POFV via-fill, Standard-PCBA top-side SMT + wave THT. As-billed at the qty-10 batch (order W2026071513250534, Jul 15 2026 — [purchases.md](/hardware/ledger/purchases.md)): $702.00 all-in ÷ 10 = **$70.20/board delivered**. Full on-board inventory (every LCSC part, per-part cost, second-sources) in the main board's own BOM: [`pcb/pcba/jlcpcb-parts.md`](/hardware/pcb/pcba/jlcpcb-parts.md) + `pcb/pcba/out/pcba.bom.csv`. | 1 | $70.20 | $70.20 <!--@electronics--> |
| [Duracell CR2032 3 V lithium cell (9-ct)](https://www.amazon.com/dp/B0C15WJXL2) | BT1's cell — the DS3231 timekeeping backup, retained by the on-board KH-CR2032-2-1 base (on the main board above); ships in the unit, seated at bench test. Order #114-3384762-6934634 Feb 22: $12.00 ÷ 9 = $1.33/ea | 1 (of 9 pk) | $1.33 | $1.33 <!--@electronics--> |
| [Waveshare ESP32-S3-Touch-LCD-4.3B](https://www.amazon.com/dp/B0D925SBYF) | The enclosure display: flavor-image/ratio tuning, clean cycles, pump priming, factory reset, screensaver, and the BLE bridge to the iOS app. 4.3" 800×480 IPS RGB capacitive touch (ST7262 RGB + GT911 touch via CH422G I/O expander), ESP32-S3-WROOM-1-N16R8 (Wi-Fi/BLE 5, 16 MB flash / 8 MB PSRAM); 7–36 V screw-terminal input off the 12 V bus (rides the J9 loom, SIG-7). The faucet display + flavor toggle live on the faucet touch LCD (below). Order #112-5620567-3321809 Jun 13: $42.99 + $3.12 tax = $46.11 | 1 | $46.11 | $46.11 <!--@electronics--> |
| [Waveshare ESP32-S3 1.47" Touch LCD, 172×320 (B0FCF1MGT3)](https://www.amazon.com/dp/B0FCF1MGT3) | **Faucet display + touch toggle.** 1.47" IPS capacitive touch (JD9853 driver + AXS5106L touch chip), ESP32-S3R8 (Wi-Fi/BLE 5). Shows the selected flavor and switches flavor by touch — no separate physical button. Mounts on the gooseneck; talks to the base ESP32 over the J3 TTL UART (SIG-6). Order #112-7687617-6094631 Jun 7: 2 @ $23.99 + $3.48 tax = $51.46 ÷ 2 = $25.73/ea | 1 | $25.73 | $25.73 <!--@electronics--> |
| [Mean Well IRM-90-12ST, 80 W / 12 V / 6.7 A, encapsulated](https://www.amazon.com/dp/B0CNRST18V) | Plan A supply and enclosure baseline; [conditional electrical Plan B](/future/carbonation-plan-b.md). 12 V supply for the low-voltage bus; IEC 60335-1 household-appliance safety listed | 1 | $31.66 | $31.66 <!--@electronics--> |

## 2. Carbonator (custom fabrication — plan A: round tube + 1/4" plates, 316L)

An earlier racetrack-body alternative (304 SS body half-sheets + dished racetrack end caps + 4× weld bungs) is no longer in active development; its parts inventory remains tracked in [purchases.md](/hardware/ledger/purchases.md) §1, and the artifacts are preserved at the `archive-plan-b` git tag, in case the round-tube path is ever blocked.

| Part | Notes | Qty | Unit $ | Line $ |
|---|---|---:|---:|---:|
| OnlineMetals #12498 — 5" OD × 0.065" wall 316 welded SS round tube | cut to 6.0" length (MTRs required); OnlineMetals #1020857414 Apr 24: 10 @ $67.35 + ship + tax = $736.73 ÷ 10 = $73.67/ea | 1 | $73.67 | $73.67 <!--@pipes--> |
| SendCutSend 1/4"-thick 316 SS circular endcap plate (`endcap-circular-2hole.dxf`) | 4.860" diameter with 2× 7/16" tap-pilot holes for 1/4" NPT; SCS SG019619 Apr 24: 20 @ $28.96 + tax = $621.19 ÷ 20 = $31.06/ea; [2](END_CAPS) plates per carbonator | 2 | $31.06 | $62.12 <!--@cut-parts--> |
| [TAISHER 2PCS 316L SS 90° Barstock Street Elbow, 1/4" NPT M × 1/4" NPT F](https://www.amazon.com/dp/B0CZ38MYL1) | all four carbonator-port elbows (water inlet + carbonated-water outlet + CO2 inlet + PRV port); assembly in [`assembly/pressure-vessel.md`](/hardware/assembly/pressure-vessel.md). [4](CARBONATOR_PORTS) elbows per build = 2 packs/build. Amazon 112-6323725 May 13: $20.99 + $1.52 tax = $22.51 ($11.26/ea × 4 = $45.04) | 4 (2 pk) | $11.26 | $45.04 <!--@plumbing--> |
| [Water-inlet jet cap, 316 SS, nominal Ø9.5 × 2 mm with 1/16-inch passage](https://www.amazon.com/dp/B0FYCJJXCS) | Cut from the Hosifiy nominal 3/8-inch × 400 mm rod; welded to the tank-facing end of the existing Port 2 elbow. Fit, root fusion and flow require the [qualification procedure](/hardware/assembly/water-inlet-jet.md). Order 112-0884852-3444230: $10.71/rod. Provisional yield is 30 caps: six 60 mm handling blanks, five caps per blank at 4 mm pitch (2 mm cap plus cutting/finishing allowance), with the 40 mm gripping tails and blank-separation waste fully allocated. $10.71/30 = $0.36 each. Actual yield, rejected coupons and tool wear remain unmeasured; initial destructive qualification is development stock. | 1 cap (1/30 rod allowance) | $0.36 | $0.36 <!--@carbonation--> |
| [Millrose 70894 Nickel Guard anti-seize PTFE tape](https://www.amazon.com/dp/B07C9ZV4PG) | The unit's PTFE anti-seize / thread-seal tape (10% nickel flake, for SS-on-SS anti-galling), a 1/2" × 600" roll — the production thread tape for **every** NPT joint in the build, not just the carbonator: the [4](CARBONATOR_PORTS) SS-into-SS carbonator ports taped twice (hydro-test plugs + final fittings, per [`assembly/pressure-vessel.md`](/hardware/assembly/pressure-vessel.md)) plus the ≥8 water/CO2 plumbing joints (per [`assembly/internal-plumbing.md`](/hardware/assembly/internal-plumbing.md)) ≈ ~16 taped joints × ~4–5" ≈ ~75"/build, so the 600" roll covers ~8 builds. Amazon 112-0019658 Apr 4: $21.52 ÷ 8 = $2.69/build | ~1/8 roll (~75") | $2.69 | $2.69 <!--@consumables--> |
| [Tap Magic EP-Xtra pipe-tap cutting fluid, 16 oz (size variant on listing B00DHMHSGM)](https://www.amazon.com/dp/B00DHMHSGM) | required for hand-tapping 1/4" NPT into 1/4"-thick 316 SS plate; ~$0.50 of fluid per carbonator | 1 | $0.50 | $0.50 <!--@consumables--> |
| [Cantesco P101S-A red visible dye penetrant, solvent-removable aerosol](https://www.amazon.com/dp/B00T46ZH5E) | Dye-penetrant (PT) inspection of the two closure fillet welds before hydro, per [`assembly/pressure-vessel.md`](/hardware/assembly/pressure-vessel.md) step 6. One 16 oz can sprays ~20 carbonators' worth of ~32" fillet; $24.45/20 | 1 (of ~20) | $1.22 | $1.22 <!--@consumables--> |
| [Cantesco D101-A non-aqueous wet developer, white, 12 oz aerosol](https://www.amazon.com/dp/B008BJCOLK) | PT developer — pulls the penetrant back out of a defect as a visible red indication on white. Misted thin over the same two welds; ~20 vessels per can; $15.88/20 | 1 (of ~20) | $0.79 | $0.79 <!--@consumables--> |
| [Lint-free cleanroom wipes, 9" × 9", cellulose/polyester Grade A (150 pcs)](https://www.amazon.com/dp/B0GD16CMYL) | PT penetrant wipe-off + the low-lint reading surface; dampened with isopropyl alcohol, never sprayed on the part. ~6 wipes per carbonator. Amazon 112-1089976 Jun 16: $17.15 ÷ 150 = $0.1143/ea, so the pack is 25 builds | 6 (of 150) | $0.11 | $0.69 <!--@consumables--> |
| 100% RTV silicone caulk (e.g. GE Silicone II) | **SKU TBD.** The weather bead on the PRV-shroud subassembly — run around the shroud-to-elbow joint and tooled to a fillet with a wet fingertip, per [`printed-parts/cold-core/prv-shroud/README.md`](/hardware/printed-parts/cold-core/prv-shroud/README.md) step 4. 100% silicone, not a latex/acrylic caulk. A few mL per build; one tube covers many. | ~1 bead (of 1 tube) | — | — <!--@consumables--> |
| [Control Devices SV-125 safety valve, 1/4" NPT, 125 psi set pressure, 49 SCFM relief, brass](https://www.amazon.com/dp/B01G2F6EMY) | Port 4 carbonator PRV (top plate, dedicated); sizing rationale in [`assembly/pressure-vessel.md`](/hardware/assembly/pressure-vessel.md). Amazon 112-6323725 May 13: $7.49 + $0.54 tax = $8.03 | 1 | $8.03 | $8.03 <!--@plumbing--> |
| neoFlo black 1/4" OD LLDPE tubing, 100 ft (FWS, WEBFWS100673540) | **PRV vent line** — what the SV-125 discharges INTO the appliance through. The valve pops into the `prv-shroud` cup that keeps the pour off it, and the cup vents through a ⌀6.35 bore in its barrel's underside, falls one corner and leaves by the shell's +Y FLANK, standing proud into the chase on the appliance's west wall. It is short because tube length on a relief path is discharge taken off the valve's rating. Unpressurized except during a relief event. [25 mm](PRV_VENT_MM) of it is drawn inside the core (`cold-core-layout`, line `prv-vent`); with the shroud's own bore and the wall chase beyond it, call it ~0.3 ft/build, cut from the same black spool §3 draws on at the blue riser's $0.171/ft | ~0.3 ft (of 100 ft) | $0.17 | $0.05 <!--@plumbing--> |
| [Cambro 6 QT polycarbonate square container](https://www.amazon.com/dp/B001BZEQ44) | citric acid passivation soak tub — holds the ~1 qt of 4% citric solution the carbonator soaks in during passivation (the acid is its own line below). Reused build-to-build, not consumed — the per-unit item is the fresh solution, not the tub; the polycarbonate is replaced only when repeated soaks craze/cloud it, ~20 builds conservatively. Amazon 112-5291452 Apr 12: $21.45 ÷ 20 = $1.07/build | 1 (of ~20) | $1.07 | $1.07 <!--@consumables--> |
| [Viva Doria food-grade citric acid, 2 lb bag](https://www.amazon.com/dp/B0C5NQM8S1) | passivation: ~1 qt of 4% solution per carbonator; 1/20 of $9.99 bag | 1 | $0.50 | $0.50 <!--@consumables--> |
| [STARTECHWELD ER316L .030 MIG wire, 10-lb spool](https://www.amazon.com/dp/B09BKFBXT9) | filler for the plate-to-tube and float-rod-to-plate laser welds; filler-alloy rationale in [`assembly/pressure-vessel.md`](/hardware/assembly/pressure-vessel.md); ~12 g of wire per ~32" of weld per carbonator × ~378 builds per 10-lb spool; $129.50/378 | 1 (of 378) | $0.34 | $0.34 <!--@welding--> |

## 3. Water inlet (tap → filter → backflow → pump → top-plate port)

The appliance ships with the water filter included, mounted **external to the enclosure**: the customer mounts it inline upstream of the rear-wall inlet, the familiar fridge-line install pattern. The ~Ø63 × 311 mm filter cartridge is longer than the enclosure's 283 mm interior width, and annual replacement happens on the customer's side of the wall, no tools. In the box, sized to the customer's 1/4" OD line, on our side of "the kit includes everything you need."

| Part | Notes | Qty | Unit $ | Line $ |
|---|---|---:|---:|---:|
| [Waterdrop 15UC-UF 0.01 µm inline water filter, 1/4" QC both ends](https://www.amazon.com/dp/B085G9TZ4L) | Upstream water filter; 1/4" QC fittings on both ends drop straight into the customer-side 1/4" LLDPE run, external to the enclosure per the section header above. Same SKU already in `purchases.md §3` (ACQUIRED). | 1 | $62.99 | $62.99 <!--@water-filter--> |
| [Multiplex 19-0897 ASSE 1022 backflow preventer](https://www.midwestbev.com/products/asse-1022-backflow-preventer) | midwestbev MB11053 Apr 24: 4 @ $29.33 = $117.32 + $28.48 ship = $145.80 ÷ 4 = $36.45/ea | 1 | $36.45 | $36.45 <!--@plumbing--> |
| [John Guest PI4512F6S female flare adapter, 3/8" tube × 3/8" FFL](https://www.freshwatersystems.com/products/john-guest-female-adapter-flare-3-8-x-3-8-flare) | **ASSE 1022 outlet adapter, piece 1 of 2** — its chrome swivel nut draws up onto the Multiplex 19-0897's 3/8" MFL outlet (flat-faced flare seal, no PTFE tape, 5/8-18 UNF 45° flare) and its 3/8" collet faces downstream into the reducer below. Gray acetal, nitrile O-ring, lead-free, 150 psi @ 68 °F. The pair is modeled as one stack at [`/hardware/reference/flare38-14ptc/`](/hardware/reference/flare38-14ptc/). No single-piece 3/8"-flare × 1/4"-push adapter exists in a potable grade — verified across John Guest acetal + lead-free brass, DMfit, neoFit, G.A. Murdock and Parker; the flare side of every family stops at a 3/8" tube. FWS order WEBFWS100693702 Jul 24: bag of 10 @ $27.44 = $2.744/ea + 33.46% allocated order overhead ($13.42 ship + $4.95 tax on a $54.90 subtotal) = $3.662/ea. **Confirm at the bench that the 19-0897's outlet is a standard SAE 45° flare and not an inverted flare.** | 1 (of 10 pk) | $3.66 | $3.66 <!--@plumbing--> |
| [John Guest PP061208W reducer, 3/8" stem × 1/4" PTC](https://www.freshwatersystems.com/search?q=PP061208W) | **ASSE 1022 outlet adapter, piece 2 of 2** — pushes into the PI4512F6S's 3/8" collet above and presents the 1/4" PTC the LLDPE runs from, so the whole path downstream of the backflow preventer runs 1/4" and steps back up to 3/8" only at the G Ganen barbs. The 3/8" run begins and ends inside the two fittings. FWS $1.83 + 20.35% overhead = $2.20/ea. | 1 | $2.20 | $2.20 <!--@plumbing--> |
| [John Guest PP0208E 1/4" union tee, black polypropylene (bag of 10)](https://www.freshwatersystems.com/products/john-guest-union-tee-black-polypropylene-1-4) | **water-split** — the 1/4" union tee on the ASSE 1022's 1/4" outlet: its **run** carries the feed straight down the fittings lane (south collet in off the outlet stack, north collet on to the neoFit flow regulator → V-A) and its **branch** stands UP, turning V-K's share out of the lane toward the G Ganen suction (flavor tap, [`fluid-topology.md`](/hardware/topology/fluid-topology.md) segment 1). Reference model at [`/hardware/reference/water-split/`](/hardware/reference/water-split/). Same JG black-PP NSF 51 + 61 SKU as the §3 install-kit union tee below and the §8 manifold tees; priced at the install-kit tee's delivered $2.57/ea (FWS bag of 10 @ $21.34 + 20.35% overhead = $25.68/bag = $2.57/each). | 1 (of 10 pk) | $2.57 | $2.57 <!--@plumbing--> |
| [neoFit ABU44M-E black 4 mm bulkhead](https://www.freshwatersystems.com/products/neofit-acetal-black-bulkhead-connector-4mm-5-32-tube) | Dedicated rear-wall **OVER** port, M15 × 1.5 barrel; white chip and 4 mm socket identify the separate atmospheric vent circuit. [Drain assembly](/hardware/assembly/asse-drain.md). FWS single-unit list $2.78; shipping and tax unallocated. | 1 | $2.78 | $2.78 <!--@plumbing--> |
| [Printed ASSE drain adapter](/hardware/printed-parts/asse-drain-adapter/README.md) | Direct TPU 85A sleeve from the vent barb to 4 mm LLDPE; 6.10 / 3.80 mm trial sockets, 14 mm tube insertion, two independent four-inch ties (§11). Unprinted fit candidate. Soft stock is allocated with the TPU seals (§8). | 1 | — | — <!--@plumbing--> |
| [neoFlo LLDPE4M-WHITE, white 4 mm OD LLDPE tube](https://www.freshwatersystems.com/products/white-4mm-od-lldpe-polyethylene-tubing) | Internal ASSE return plus continuous umbilical/faucet drain. Allow 8 ft/build including the 2000 mm factory faucet cut and internal return/trim. FWS 25 ft @ $4.50 = $0.18/ft. The [neoFlo manufacturer sheet](https://assets.freshwatersystems.com/image/upload/s--N9disqrx--/gjtidjfc0tlprqbhb4ka.pdf) specifies 2.5 mm ID and R25 minimum bend radius. Shipping and tax unallocated. | ~8 ft (of 25 ft) | $0.18 | $1.44 <!--@plumbing--> |
| [neoPure reinforced clear PVC tubing, 3/8" ID × 0.594" OD (10 ft)](https://www.freshwatersystems.com/products/reinforced-clear-pvc-tubing-3-8-id-x-594-od) | **The two G Ganen port hoses, water-6 and water-7.** Each joins its separately measured pump barb to the corresponding MAACFLOW adapter, with one SAE #6 clamp at each end. The reinforced-PVC routes preserve the measured port axes and a 15.9 mm minimum bend radius. Cut lengths come from the current assembly tube schedule; ~0.85 ft/build is the costing allowance. **225 psi @ 70 °F** tubing rating; NSF 61 certified for direct contact with potable water, FDA, RoHS, REACH, USP Class IV, phthalate-free; Tygon B-44-4X I.B. compatible. FWS order WEBFWS100693702 Jul 24: $6.12/10 ft = $0.612/ft + 33.46% allocated order overhead = $0.817/ft | ~0.85 ft (of 10 ft) | $0.82 | $0.69 <!--@plumbing--> |
| [FWS Basics 316 SS hose clamp, SAE #6 (3/8"–7/8")](https://www.freshwatersystems.com/products/stainless-steel-hose-clamp-316-sae-6-3-8-7-8) | Worm-gear clamps on the two pump-port stubs, **2 per stub** (one over the pump's molded barb, one over the adapter's barb) — 4/build. The reinforced PVC is Ø15.1 OD and stretches to ~17 mm over a barb, so SAE #6 carries the pump joints. **316 SS**, matching the GAGIRA 316L coupling (§3) and the TAISHER carbonator-port elbows (§2) — these carry the wet pump-hose joints. FWS order WEBFWS100693702 Jul 24: pack of 10 @ $21.34 = $2.134/ea + 33.46% allocated order overhead = $2.848/ea | 4 (of 10 pk) | $2.85 | $11.39 <!--@plumbing--> |
| [G Ganen 12 V diaphragm pump](https://www.amazon.com/dp/B07F35PTFR) | Derek's selected received pump. The [measured reference](/hardware/reference/g-ganen-pump/README.md) supplies its rigid housing, independent barb profiles and four identical sliding rubber feet with nominal 7 mm pads. The selected full-engagement slot centres are reference X=9.5/67.5 mm, Y=±38.5 mm; installed discharge points toward enclosure −X. Advertised 110 psi / 4.5 L/min are separate listing limits; actual electrical and hydraulic performance are established at commissioning. Amazon 112-0884852-3444230 Sep 15: $19.29 delivered ([purchases.md §4](/hardware/ledger/purchases.md)). | 1 | $19.29 | $19.29 <!--@pumps--> |
| [MAACFLOW SS 1/4" NPT M × 3/8" hose barb (4-pk)](https://www.amazon.com/dp/B0DMP77B6S) | Two adapters connect the G Ganen port hoses to the 1/4" LLDPE circuit. **Suction:** pump → reinforced-PVC hose → MAACFLOW → PP450822E. **Discharge:** pump → reinforced-PVC hose → MAACFLOW → GASHER check → PP450822E. The made-up fitting chains sit on their own cap anchors; the separately routed hoses meet each measured pump barb. Retained reference paths are `reference/seaflo-suction-chain` and `reference/seaflo-discharge-chain`. 2 of 4 per unit | 2 (of 4 pk) | $3.24 | $6.48 <!--@plumbing--> |
| [GASHER 1/4" NPT one-way check valve, male × female (2-pk, $15.00)](https://www.amazon.com/dp/B0FV2D2FFX) | water-side check between G Ganen pump and top-plate water-inlet port; construction and verification in [`assembly/cold-core.md`](/hardware/assembly/cold-core.md) "Warm-side check valves"; 1 of 2 valves per unit (the other valve is the CO2-side check in §4). **Male × female, not F × F**: the casting's arrow runs from the female socket to the male stub, so the female end takes the upstream MAACFLOW's male NPT and the male stub threads into the PP450822E below it. Exact body/seat materials and pressure rating remain unverified because the source descriptions conflict; see the [part reference](/hardware/reference/gasher-check-valve/README.md). $15.00 the 2-pack paid, $7.50/ea | 1 (of 2) | $7.50 | $7.50 <!--@plumbing--> |
| [John Guest PP010822E 1/4" OD × 1/4" NPT male connector, black polypropylene (10-pk)](https://www.freshwatersystems.com/products/john-guest-male-connector-nptf-black-polypropylene-1-4-x-1-4-nptf) | 1/4" NPT **M** × 1/4" PTC adapter, 2 on the water-inlet path: filter → GAGIRA inlet (its 1/4" NPT F small end), and the cold-side of the +Z slot transition (into the TAISHER carbonator-port elbow's 1/4" NPT F). The two joints that face a male thread take the PP450822E female adapter below instead. FWS WEBFWS100675224 May 15: $11.00 + $5.23 ship + $1.18 tax = $17.41 ÷ 10 = $1.741/ea | 2 (of 10 pk) | $1.74 | $3.48 <!--@plumbing--> |
| [John Guest PP450822E female adapter, 1/4" OD × 1/4" NPTF, black polypropylene (bag of 10)](https://www.freshwatersystems.com/products/john-guest-female-adapter-nptf-black-polypropylene-1-4-x-1-4-nptf) | 1/4" NPT **F** × 1/4" PTC adapter — the two joints on the water path where the neighbour presents a male thread and a male connector cannot go: the **suction** (1/4" LLDPE → PP450822E → MAACFLOW's 1/4" NPT M → 3/8" suction barb) and the **discharge** (GASHER's male outlet stub → PP450822E → 1/4" LLDPE → cold core). Black PP, EPDM O-ring, lead-free, NSF 51 + NSF 61, 150 psi @ 70 °F — same JG black-PP food-cert family as the PP010822E above. FWS bag of 10 @ $34.06 = $3.40/ea + 20.35% overhead = $4.09/ea | 2 (of 10 pk) | $4.09 | $8.18 <!--@plumbing--> |
| [GAGIRA 316L SS reducing coupling, 3/8" NPT F × 1/4" NPT F (5-pk, incl. Teflon tape)](https://www.amazon.com/dp/B0G2XJGZMQ) | **Upstream adapter chain — closes the 1/4 JG QC → ASSE 1022 inlet gap.** Threads onto the PP010822E's 1/4" NPT M side (above) on the small end and onto the ASSE 1022's 3/8" MPT inlet (below) on the large end. **316L SS** — food-service gold standard, no lead concerns, matches the TAISHER 316L SS carbonator-port elbows (§2) and the 316L carbonator walls themselves (§2); strictly stricter than lead-free brass would have been. Includes Teflon tape (bonus — Millrose PTFE tape is the production tape per `assembly/internal-plumbing.md`). Amazon 114-6677442 May 22: 5 @ $16.99 + $1.23 tax = $18.22 ÷ 5 = $3.644/ea | 1 (of 5 pk) | $3.64 | $3.64 <!--@plumbing--> |
| [neoFit acetal black flow-control bulkhead, 1/4" tube (ABCVU44-E)](https://www.freshwatersystems.com/products/neofit-acetal-black-flow-control-bulkhead-1-4-tube) | **Flow regulator on the V-A clean-water feed** — the "flow regulator → V-A" node on the water-split's north run (§3 above) and in [`/hardware/topology/fluid-topology.md`](/hardware/topology/fluid-topology.md) (tube segment 1). Adjustable flow-control valve in bulkhead form; the screw throttles the clean/tap-water feed down so the flavor manifold runs at its low (<10 PSI) working pressure (`docs/plumbing.md` "Why a Needle Valve Instead of a Pressure Regulator"). Push-connect 1/4", acetal + food-grade EPDM, NSF 51/61, FDA, 150 psi @ 68°F, black. FWS WEBFWS100707201 Sep 16: bag of 10 @ $43.45 × ($364.06 paid / $312.00 merchandise) / 10 = $5.0700/ea, including allocated shipping and tax. **ON-ORDER ×10** ([purchases.md §3](/hardware/ledger/purchases.md)). | 1 | $5.07 | $5.07 <!--@plumbing--> |
| [neoFlo White 1/4" OD LLDPE tubing, 100 ft (LLDPE4-WHITE)](https://www.freshwatersystems.com/products/white-1-4-od-lldpe-polyethylene-tubing) | **Every tap-water line inside the cabinet.** White is what a colour means for tap water on the rear face ([`printed-parts/enclosure/y-wall-of-back-top/_y_wall_dimensions.py`](/hardware/printed-parts/enclosure/y-wall-of-back-top/_y_wall_dimensions.py) `port_colors`), so the line inboard of the white-ringed bulkhead is the colour of the ring it comes through — the same pairing the blue riser makes in §3 and the red tether in §4. Covers the **water-inlet run** (rear-wall PP1208E bulkhead → Waterdrop filter → PP010822E adapter chain), `water-2`…`water-5` down the west lane to the G Ganen and on to the `water-in` cap conduit, and the flavour circuit's own tap-water leg `fluid-1`/`fluid-2`/`fluid-3` — the split's branch, the flow regulator, and V-A's outlet into Y-A, which is the last of the tap water before the funnel's syrup meets it at Y-A. Push-connect ends are made by the filter's own 1/4" QC and the JG PTC fittings — no separate quick-connects. Same neoFlo LLDPE family, NSF 51 + FDA, as the §3 blue riser and the §4 red tether. FWS WEBFWS100707201 Sep 16: $12.00/100 ft × ($364.06 paid / $312.00 merchandise) = $14.0023 per 100 ft = $0.14002/ft, including allocated shipping and tax. **ON-ORDER 100 ft** ([purchases.md §3](/hardware/ledger/purchases.md)). | ~7 ft (of 100 ft) | $0.14 | $0.98 <!--@plumbing--> |
| neoFlo black 1/4" OD LLDPE tubing, 100 ft (FWS, WEBFWS100673540) | **Every flavour line, both channels.** Black is what a flavour line is on this machine, and the rear face's two flavour rings are the wall's own black. Covers the flavour manifold's own segments ([`topology/fluid-topology.md`](/hardware/topology/fluid-topology.md) "Tube Segments", all but `fluid-3`), `fluid-4` down from the funnel union, and the six runs out of the manifold to the reservoirs and the two rear flavour bulkheads. The same spool feeds the 2 flavor risers to the faucet per [`assembly/faucet-and-umbilical.md`](/hardware/assembly/faucet-and-umbilical.md) — to the printed tip on a Black faucet, to their unions on a White one (§9), the PRV vent line (§2), and the funnel's drain stub ([`reference/funnel-drain-stub`](/hardware/reference/funnel-drain-stub/), card SA-06), which is why the stub takes the same collet every other line on the machine hands over on. Same neoFlo 1/4" LLDPE (NSF 51, FDA) as the §3 blue riser, just black. ~8 ft/build in the cabinet at the blue riser's $0.171/ft. | ~8 ft (of 100 ft) | $0.17 | $1.37 <!--@plumbing--> |
| [John Guest PP1208E 1/4" OD black polypropylene push-to-connect bulkhead union (10-pk)](https://www.amazon.com/dp/B00JYFU8MM) | **Rear-wall customer-facing water inlet.** The customer plugs the install-kit 1/4" LLDPE into this bulkhead — push-to-connect, no tools. 1/4" QC on both sides (interior side feeds into the in-cabinet run → Waterdrop filter → PP010822E → GAGIRA 316L SS coupling → ASSE 1022 3/8" MPT inlet). Black PP, NSF 51 + NSF 61, FDA-compliant materials, EPDM O-ring, 150 psi @ 70°F; same SKU and panel hole as the §8 umbilical bulkheads. Amazon 112-6407862 May 11: $24.79 ÷ 10 = $2.479/ea. | [1](PP1208E_INLET) (of 10 pk) | $2.48 | $2.48 <!--@plumbing--> |
| [John Guest Speedfit ASVPP1LF angle stop adapter valve, 3/8" × 3/8" × 1/4"](https://www.freshwatersystems.com/products/john-guest-angle-stop-adapter-valve-lead-free-3-8-x-3-8-x-1-4) ([B003YKF2JC](https://www.amazon.com/dp/B003YKF2JC)) | **Install-kit tee, scenario B (older home).** Threads between the customer's existing 3/8" chrome angle stop and its braided riser — female compression swivel down onto the stop, male compression thread up for the riser — and offers a **1/4" push-to-connect branch** for the appliance's white run. One wrench, at the two 3/8" joints only; the branch the customer makes is the same push as every other joint in this kit, and needs no ferrule, nut or insert. Carries its own quarter-turn shutoff on that branch. White polypropylene body, EPDM seals, lead-free brass threads, NSF 61, 150 psi @ 70 °F — the same John Guest family as every other fitting on this water path. FWS WEBFWS100707201 Sep 16: 10 singles @ $12.13 = $121.30 × ($364.06 paid / $312.00 merchandise) / 10 = $14.1540/ea, including allocated shipping and tax. **ON-ORDER ×10** ([purchases.md §3](/hardware/ledger/purchases.md)). | 1 | $14.15 | $14.15 <!--@plumbing--> |
| [John Guest PP0208E 1/4" union tee, black polypropylene (bag of 10)](https://www.freshwatersystems.com/products/john-guest-union-tee-black-polypropylene-1-4) | **Install-kit tee, scenario A (modern home).** Drops inline into an existing 1/4" LLDPE under-sink line (push-to-connect, no tools) — the configuration shipped in any kitchen new since the late 2010s or any kitchen with a PEX manifold + ice-maker / RO / drinking-water stub-out. **Black PP, NSF 51 + 61, FDA-compliant materials** — same JG black-PP food-cert family as the §3 PP010822E, §3 PP450822E, and §8 PP1208E already in the BOM. FWS WEBFWS100677333 May 22: 1 bag of 10 @ $21.34 + allocated 20.35% overhead = $25.68/bag = $2.57/each × 1/build; bag of 10 = 10 builds of stock. Reference model at [`/hardware/reference/jg-pp0208e-tee/`](/hardware/reference/jg-pp0208e-tee/), off John Guest's own Equal Tee data sheet. | 1 (of 10 pk) | $2.57 | $2.57 <!--@plumbing--> |
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

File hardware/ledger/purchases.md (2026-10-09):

# Purchases

Project purchase ledger for the Home Soda Machine. Current scope: **2026**; IDs and the analytical schema support additional calendar years. Rows record project purchase values, quantities and fulfillment independently of payment evidence.

- [bom.md](/hardware/ledger/bom.md) allocates parts to one appliance.
- [tools.md](/hardware/ledger/tools.md) describes reusable tooling.
- [inventory.md](/hardware/ledger/inventory.md) describes current inventory and received items.

These views overlap the purchase ledger and are not additional expenditures. Each purchase row carries a persistent `purchase_id` in its inline comment. Keep that comment when moving or editing a row. [purchases.evidence.json](/hardware/ledger/purchases.evidence.json) owns source classifications, order relationships and distinct merchant charge/refund events; row costs remain here. See [the schema and private reconciliation contract](/hardware/ledger/purchases.schema.md) and [audit guidance](/hardware/ledger/purchases.audit.md).

Amounts include recorded project tax, shipping and item-specific tariffs. They are explicitly classified as a final vendor amount, an estimate or legacy/unverified in the analytical exports. A bundle, shipment or order price is a row total; only a price explicitly marked `ea` is multiplied by quantity. Fulfillment status does not establish whether a charge or refund occurred.

The generated procurement valuation includes ACQUIRED, ON-ORDER, MISSING and REPLACED purchases plus engineering services. It includes estimates and amounts whose payment evidence is unknown. Merchant-evidenced payments are a separate view and must not be added to the procurement valuation.

---

## 1. Carbonator fabrication

Stainless carbonator fabrication: 316 SS round-tube body + 1/4" laser-cut 316 SS end-cap plates (direct-tapped 1/4" NPT), welding/forming tools, drill-tap tooling, and the hydro/pressure-test rig. Racetrack 304 SS stock is retained as fallback (see [inventory.md](/hardware/ledger/inventory.md)).

| Part | ASIN link | Qty | $ | Order # | Ordered | Delivered | Status |
| --- | --- | --- | --- | --- | --- | --- | --- |
| <!--purchase:pur-7542b7b3a08841d0aa54037f1954c0ab--> VEVOR Slip Roll Machine, 24" forming width, 16 ga | [B0DZP1VBZY](https://www.amazon.com/dp/B0DZP1VBZY) | 1 | $235.94 | 112-4780540-1769027 | 2026-04-16 | — | ACQUIRED |
| <!--purchase:pur-91bf8d5d3cfe41f096b1ae148d3fd635--> VEVOR 12-ton Hydraulic Shop Press (for dishing dies) | [B0BZ7YY3CP](https://www.amazon.com/dp/B0BZ7YY3CP) | 1 | $155.50 | 112-1627637-9419449 | 2026-04-14 | 2026-04-22 | ACQUIRED |
| <!--purchase:pur-ce509f485e7a42ccbaa45ec2f97e306b--> Weldpro 3-Tier Welding Cart | [B08G5CW3DY](https://www.amazon.com/dp/B08G5CW3DY) | 1 | $193.04 | 112-8830635-1424267 | 2026-04-06 | — | ACQUIRED |
| <!--purchase:pur-e072750dd8ce4f27b3713d63641fdd06--> Blue Demon ER308L .030 stainless MIG wire, 2 lb | [B0025Q2HIU](https://www.amazon.com/dp/B0025Q2HIU) | 1 | $23.95 | 112-8830635-1424267 | 2026-04-06 | — | ACQUIRED |
| <!--purchase:pur-cebd01564d414f5db4d40f5871647c0c--> RX Weld argon regulator / flowmeter | [B08P5BNHBX](https://www.amazon.com/dp/B08P5BNHBX) | 1 | $31.09 | 112-8830635-1424267 | 2026-04-06 | — | ACQUIRED |
| <!--purchase:pur-15aa744ac25044dfbfa60c8ba73be920--> Airgas #8162013342 — argon size-80 cylinder, CGA-580 (CY-AR 80) | airgas.com (Lincoln NE) | 1 | $399.31 | — | — | — | ACQUIRED |
| <!--purchase:pur-438e546fcfdc40feb6642cdbf2b74d04--> Airgas #8162013342 — argon fill, 85 SCF (AR 80) | airgas.com (Lincoln NE) | 1 | $75.20 | — | — | — | ACQUIRED |
| <!--purchase:pur-221ddf9f8004473dbd36b14440a9a4d5--> Strong Hand magnetic V-pads welding magnet kit | [B00JXDSVA6](https://www.amazon.com/dp/B00JXDSVA6) | 1 | $29.21 | 112-8830635-1424267 | 2026-04-06 | — | ACQUIRED |
| <!--purchase:pur-ce12043d997645c7841cd5a1063bc96e--> MAXMAN stainless steel wire brush set | [B08L7RXVG5](https://www.amazon.com/dp/B08L7RXVG5) | 1 | $12.22 | 112-8830635-1424267 | 2026-04-06 | — | ACQUIRED |
| <!--purchase:pur-38a2865767ba4a9d8a2651745f62c81f--> 1/4" NPT female weld bung, 304 SS stepped flange | [B07QNV8796](https://www.amazon.com/dp/B07QNV8796) | 5 | $8.57 ea | 112-0019658-3684217 | 2026-04-04 | — | ACQUIRED |
| <!--purchase:pur-c42545bec1f74aa8b33c3976c8988412--> 4pc 1/4" NPT male hex nipple, 316 SS 5000 psi | [B0GD1QBLQ3](https://www.amazon.com/dp/B0GD1QBLQ3) | 1 pk | $16.29 | 112-0019658-3684217 | 2026-04-04 | — | ACQUIRED |
| <!--purchase:pur-7d828979728342ebb0edb827756b63ce--> Millrose PTFE thread seal tape | [B07C9ZV4PG](https://www.amazon.com/dp/B07C9ZV4PG) | 1 | $21.52 | 112-0019658-3684217 | 2026-04-04 | — | ACQUIRED |
| <!--purchase:pur-38b2dc24443d4492a0a00ad450a8c0eb--> Viva Doria 100% pure food-grade citric acid, fine grain, 2 lb | [B0C5NQM8S1](https://www.amazon.com/dp/B0C5NQM8S1) | 1 | $9.99 | 112-8083402-8740244 | 2026-04-12 | — | ACQUIRED |
| <!--purchase:pur-7202f6a376b24f3a84ebfef95c29ef5f--> Cambro 6 QT square polycarbonate food container | [B001BZEQ44](https://www.amazon.com/dp/B001BZEQ44) | 1 | $21.45 | 112-5291452-2765065 | 2026-04-12 | — | ACQUIRED |
| <!--purchase:pur-fc68e8713b2a41ab8baef861721af0d1--> findmall ER308L .035 MIG wire, 10 lb spool | [B0C52XQB39](https://www.amazon.com/dp/B0C52XQB39) | 1 | $90.68 | 114-6485602-3013015 | 2026-04-19 | 2026-04-20 | ACQUIRED |
| <!--purchase:pur-bcc7d7c5f76048539f7859cce9e9a841--> PGN ER308L .030 MIG wire, 10 lb spool | [B09WRZDBPN](https://www.amazon.com/dp/B09WRZDBPN) | 1 | — | — | — | — | CANCELLED |
| <!--purchase:pur-764f5a241d364192abf88a18b9e465b8--> STARTECHWELD ER316L .030 MIG wire, 10 lb spool, 8" OD / 2" center bore | [B09BKFBXT9](https://www.amazon.com/dp/B09BKFBXT9) | 1 | $129.50 | 112-2295053-5101056 | 2026-04-24 | 2026-04-27 | ACQUIRED |
| <!--purchase:pur-bc22bede88dd4e12ae96ae067accce8e--> Caiman premium goat-grain TIG / multi-task welding gloves | [B07T6VLSK3](https://www.amazon.com/dp/B07T6VLSK3) | 1 | $23.05 | 114-0933175-3371439 | 2026-04-19 | 2026-04-20 | ACQUIRED |
| <!--purchase:pur-e615fc3b8063460eb1fa005c1c4f5577--> Caiman premium goat-grain TIG welding gloves | [B07T1NYXHM](https://www.amazon.com/dp/B07T1NYXHM) | 1 | $23.05 | 114-5597505-0433853 | 2026-04-17 | 2026-04-18 | ACQUIRED |
| <!--purchase:pur-c887374045604177851c4a81cc779f0e--> YTKavq 1/4" × 2" × 12" C110 pure copper flat bar, soft-annealed | [B0DR2PX6TT](https://www.amazon.com/dp/B0DR2PX6TT) | 1 | $42.89 | 112-4953236-4101019 | 2026-04-23 | 2026-04-24 | MISSING (delivered-but-empty 2026-04-23; no refund pursued) |
| <!--purchase:pur-503ab7c363e14bc6a3b241f8f86b3afd--> YTKavq 1/4" × 2" × 12" C110 pure copper flat bar | [B0DR2PX6TT](https://www.amazon.com/dp/B0DR2PX6TT) | 1 | $42.89 | 112-0935480-2206657 | 2026-04-22 | 2026-04-23 | ACQUIRED |
| <!--purchase:pur-9975a463fa7c4564a160d7c783ef6b6a--> 304 SS 4" × 6" × 1/16" (16 ga / 1.5 mm) sheet, 2-pk | [B0DFXXQZD3](https://www.amazon.com/dp/B0DFXXQZD3) | 3 pk | $48.24 | 112-8776391-7335431 | 2026-04-22 | 2026-04-23 | ACQUIRED |
| <!--purchase:pur-ee913c4facd5494c8a0555d093e1030f--> 304 SS 4" × 4" × 0.04" (19 ga / 1 mm) sheet, 4 pc | [B0C5LWVLCD](https://www.amazon.com/dp/B0C5LWVLCD) | 1 | $13.93 | 112-6588057-9595403 | 2026-04-22 | 2026-04-23 | ACQUIRED |
| <!--purchase:pur-e8d314ccce9643ffbd660b3cf9bd5f66--> Drill America 1/4" NPT HSS pipe tap + 1-1/2" OD round die kit | [B0DXN1LDKT](https://www.amazon.com/dp/B0DXN1LDKT) | 1 | $20.16 | 114-8354589-7380236 | 2026-04-19 | 2026-04-21 | ACQUIRED |
| <!--purchase:pur-3e422dd818e94af4b336e62fbe83e26f--> MOTOKU 38 mm / 1.5" OD heavy-duty round die handle | [B073ZX58PH](https://www.amazon.com/dp/B073ZX58PH) | 1 | $15.00 | 114-8354589-7380236 | 2026-04-19 | 2026-04-21 | ACQUIRED |
| <!--purchase:pur-cd430b2b91584e61934c6db74a05ee07--> Tap Magic EP-Xtra pipe-tap cutting fluid, 16 oz (size variant on listing B00DHMHSGM) | [B00DHMHSGM](https://www.amazon.com/dp/B00DHMHSGM) | 1 | $17.01 | 112-3539135-2289004 | 2026-04-24 | 2026-04-25 | ACQUIRED |
| <!--purchase:pur-85b97d7e20ab4ced8690e2c8119240b0--> WEN 4208T 2.3 A 8" 5-speed benchtop drill press | [B08ZVT5JKC](https://www.amazon.com/dp/B08ZVT5JKC) | 1 | $111.54 | 112-2348373-7907448 | 2026-04-29 | 2026-05-02 | ACQUIRED |
| <!--purchase:pur-6e1e9dc55d874960be6930283c4500b5--> Drill America 1/4"–1-1/8" tap-capacity adjustable tap wrench, DWT series | [B00DMEYTLW](https://www.amazon.com/dp/B00DMEYTLW) | 1 | $33.02 | 112-2348373-7907448 | 2026-04-29 | 2026-05-02 | ACQUIRED |
| <!--purchase:pur-6a28e690dc6548aea3e927d117cd696e--> Drill America DWT64006 Qualtech HSS pipe tap, 1/4"-18 NPT | [B01DZD1Y9Y](https://www.amazon.com/dp/B01DZD1Y9Y) | 1 | $10.54 | 112-2348373-7907448 | 2026-04-29 | 2026-05-02 | ACQUIRED |
| <!--purchase:pur-d83d321239db48ee949f436e89843a22--> LingGan 1/4-18 NPT M35 cobalt steel pipe tap, TiN-coated | [B0D7HM5R3C](https://www.amazon.com/dp/B0D7HM5R3C) | 1 | $13.93 | 112-8743279-3935456 | 2026-05-17 | 2026-05-19 | ACQUIRED |
| <!--purchase:pur-00029069de0d454d9ad2c2c2eb5f845d--> Brown & Sharpe spring-loaded tap guide, 1/2" hardened shank | [B005317ZMC](https://www.amazon.com/dp/B005317ZMC) | 1 | $27.45 | 112-2348373-7907448 | 2026-04-29 | 2026-05-02 | ACQUIRED |
| <!--purchase:pur-0dc7b5eaf55e4a1d83372f6dd4b431b3--> Mollom 124 mm / 4-7/8" HSS M42 bi-metal hole saw with arbor + pilot bits | [B0BZQ4J5B1](https://www.amazon.com/dp/B0BZQ4J5B1) | 1 | $19.19 | 112-2348373-7907448 | 2026-04-29 | 2026-05-02 | ACQUIRED |
| <!--purchase:pur-d54462b1392841c58b6ec57af6d4e542--> 12 mm Baltic birch plywood, 1/2" × 8" × 8", B/BB grade (2 pc) | [B0DP8597Q2](https://www.amazon.com/dp/B0DP8597Q2) | 1 box | $10.71 | 112-2348373-7907448 | 2026-04-29 | 2026-05-02 | ACQUIRED |
| <!--purchase:pur-191fdb2c798641c2a0cb352a5b13e820--> ACXFOND 1/4" MDF boards, 8" × 10" (20 pk) | [B0F1FJYDQ3](https://www.amazon.com/dp/B0F1FJYDQ3) | 1 pk | $25.73 | 112-2348373-7907448 | 2026-04-29 | 2026-05-02 | ACQUIRED |
| <!--purchase:pur-cb555dd42adc4a74b6bdd249ca71930e--> Franklin International 1412 Titebond III wood glue, 4 oz | [B0002YQ378](https://www.amazon.com/dp/B0002YQ378) | 1 | $5.34 | 112-2348373-7907448 | 2026-04-29 | 2026-05-02 | ACQUIRED |
| <!--purchase:pur-2f14d60432b24b319fc62deac47e5bc0--> Storystore 4" heavy-duty steel C-clamps (4 pk) | [B0DHX78G97](https://www.amazon.com/dp/B0DHX78G97) | 1 pk | $21.44 | 112-2348373-7907448 | 2026-04-29 | 2026-05-02 | ACQUIRED |
| <!--purchase:pur-0d152c5e95024c63a27321be678d3556--> Bosch DSB1013 1" × 6" Daredevil Standard Spade Bit | [B001NGPAA0](https://www.amazon.com/dp/B001NGPAA0) | 1 | $5.35 | 111-4630388-1572202 | 2026-04-29 | 2026-05-01 | ACQUIRED |
| <!--purchase:pur-97a56b4c9691429f87b40c74bd003f43--> Drill Hulk DHCO26 9/64" (3.57 mm) M35 cobalt jobber twist drill bits, 12-pack — blind rod-register drilling in the 316 SS end-cap plates | [B07XNNNC5Y](https://www.amazon.com/dp/B07XNNNC5Y) | 1 pk (12) | $18.43 | 112-3161139-1981039 | 2026-06-15 | 2026-06-17 | ACQUIRED |
| <!--purchase:pur-54c8c34bd4c748ccb658353bd94fb718--> WEN BA4555 5" benchtop metal-cutting band saw — horizontal cutoff with vise + length stop, 0–60° miter, variable 125–260 FPM, 56-1/2" blade. Square, repeatable cuts of the 1/8" 316L level-sensing rods (carbonator + flavor reservoir + lite reservoir pocket) | [B09XWQCNGT](https://www.amazon.com/dp/B09XWQCNGT) | 1 | $362.73 | 112-0741371-9657825 | 2026-06-17 | 2026-06-24 | ACQUIRED |
| <!--purchase:pur-fea530ae80304ebe82ba2d6d74518e45--> Imachinist S56121224SS 56-1/2" × 1/2" × 24 TPI M42 bi-metal bandsaw blade (stainless) — 1/8" rod cutoff blade for the BA4555 | [B0B7GDTX9H](https://www.amazon.com/dp/B0B7GDTX9H) | 1 | $19.83 | 112-3334877-3267411 | 2026-06-17 | 2026-06-21 | ACQUIRED |
| <!--purchase:pur-2d770e60452041f4b4ab24b5ac7e7271--> Ultra Duster Canned Air Industrial Strength 10 oz, 4-pack | [B07JRBR1MM](https://www.amazon.com/dp/B07JRBR1MM) | 1 pk (4× 10 oz) | $24.51 | 112-6571709-7582668 | 2026-05-08 | 2026-05-12 | ACQUIRED |
| <!--purchase:pur-86cdf806ea53495db94c3f7bbd471f36--> Hgnova 15-pc 1064 nm laser protective lens, D18 × 2 mm, 1000–3000 W handheld 4-in-1 laser welder | [B0FF38DY1Z](https://www.amazon.com/dp/B0FF38DY1Z) | 1 pk (15) | $19.29 | 112-3421913-9021801 | 2026-04-30 | 2026-05-03 | ACQUIRED |
| <!--purchase:pur-6e9a8d44f2e24b729ca4888aba4b57aa--> SENCTRL 0–200 PSI glycerin-filled pressure gauge, 2.5" dial, 1/4" NPT lower mount, SS case | [B0BCHMQLFB](https://www.amazon.com/dp/B0BCHMQLFB) | 1 | $10.72 | 112-2086169-3211445 | 2026-05-04 | 2026-05-05 | ACQUIRED |
| <!--purchase:pur-8ec3b26453804ce8a9f83d81ed692d47--> ChillWaves brass 1/4" NPT outer-hex-head pipe plugs, 12-pack | [B0C4LP4B3D](https://www.amazon.com/dp/B0C4LP4B3D) | 1 pk (12) | $11.79 | 112-2086169-3211445 | 2026-05-04 | 2026-05-05 | ACQUIRED |
| <!--purchase:pur-e6d9006847b144cfbe4c52e50f295fd3--> Milton 727 industrial M-STYLE® 1/4" MNPT air plug, 10-pack, alloy steel | [B000PDWI4S](https://www.amazon.com/dp/B000PDWI4S) | 1 pk (10) | $15.02 | 112-2086169-3211445 | 2026-05-04 | 2026-05-05 | ACQUIRED |
| <!--purchase:pur-39eaa2bc1e864273b83e0f52945fef6e--> BEAMNOVA hydrostatic test pump, 0–726 PSI / 0–50 bar / 0–5 MPa, 3.17 gal water reservoir, 4.43 ft × 1/4" hydraulic hose with 1/2" female gasket-swivel testpiece end, copper pump body + check valve, built-in 3-unit dial gauge | [B07T45XTD1](https://www.amazon.com/dp/B07T45XTD1) | 1 | $93.30 | 112-6990924-2823418 | 2026-05-04 | 2026-05-05 | ACQUIRED |
| <!--purchase:pur-3f7c2f57bc594cc8abbc5e9896c1503a--> KOOTANS 1/2" NPT male × 1/4" NPT male solid brass reducing hex nipple, 4-pack | [B07P7ZRZMD](https://www.amazon.com/dp/B07P7ZRZMD) | 1 pk (4) | $12.86 | 112-1128563-6922646 | 2026-05-04 | 2026-05-05 | ACQUIRED |
| <!--purchase:pur-8fb96099b6b34dbfa04c2e6d93c55a42--> OnlineMetals #12498 — 5" OD × 0.065" wall 316 welded SS round tube, cut to 6.0" length, MTRs required | onlinemetals.com | 10 | $736.73 | 1020857414 | 2026-04-24 | — | ACQUIRED |
| <!--purchase:pur-dcfef64f3f264f2f95eb43659806718f--> SendCutSend order SG019619 — 1/4" 316 SS circular endcap plates | sendcutsend.com | 20 | $621.19 | — | — | — | ACQUIRED |
| <!--purchase:pur-0b97fae73c024c86b30887d80ae3e384--> SendCutSend order SQ65E969 — 304 SS 0.048" body blanks ×2 (plan-B spare/practice) | sendcutsend.com | 2 | $60.19 | — | — | — | ACQUIRED |
| <!--purchase:pur-fcca5d9c2ff44cdba4f21d5a544fbcef--> SendCutSend order SV07U813 — 304 SS 0.060" racetrack end-cap blanks ×4 (plan-B spare) | sendcutsend.com | 4 | $45.52 | — | — | — | ACQUIRED |
| <!--purchase:pur-5133bb7161d64ebc8dd128da8a97b6f0--> SendCutSend order SP54G453 — 304 SS 0.048" body half-sheets ×10 (plan-B spare) | sendcutsend.com | 10 | $134.38 | — | — | — | ACQUIRED |
| <!--purchase:pur-5fae169d013f41d197ba6f7e6a43c212--> SendCutSend order S064D925 — 0.060" 316 SS Touch-Flo under-counter plates | sendcutsend.com | 10 | $36.29 | — | — | 2026-05-14 | ACQUIRED |
| <!--purchase:pur-bf8d135df8f84025b5e36f07d38b311c--> SendCutSend order S4177511 — 0.060" 316 SS Touch-Flo under-counter plates | sendcutsend.com | 23 | $34.78 | — | 2026-06-18 | 2026-06-24 | ACQUIRED |
| <!--purchase:pur-ceca42852b574a18a19ff73157582131--> Cantesco P101S-A red visible dye penetrant, solvent-removable aerosol — dye-penetrant (PT) leak/crack inspection of the end-cap closure fillet welds before hydro (step 6) | [B00T46ZH5E](https://www.amazon.com/dp/B00T46ZH5E) | 1 | $24.45 | 112-1089976-3089830 | 2026-06-16 | 2026-06-17 | ACQUIRED |
| <!--purchase:pur-6a68515d88684816ad2207c514cba07b--> Cantesco D101-A non-aqueous wet developer, white, 12 oz aerosol — PT developer that draws the penetrant back out of a defect as a visible indication | [B008BJCOLK](https://www.amazon.com/dp/B008BJCOLK) | 1 | $15.88 | 112-9519199-9509821 | 2026-06-16 | 2026-06-17 | ACQUIRED |
| <!--purchase:pur-2833c10788ff489fbcdfebb7972b7522--> Cleanroom wipes, 9" × 9", cellulose/polyester Grade A 68 GSM, lint-free (150 pcs) — controlled PT penetrant wipe-off (dampened with the already-owned isopropyl alcohol, not sprayed) + low-lint surface for reading indications | [B0GD16CMYL](https://www.amazon.com/dp/B0GD16CMYL) | 1 pk (150) | $17.15 | 112-1089976-3089830 | 2026-06-16 | 2026-06-17 | ACQUIRED |
| <!--purchase:pur-f327ab43abf34b7089fb74f6bfa7a5bf--> Noga NG8150 heavy-duty deburr tool with 10 S10 HSS swivel blades — hand deburr of the 316L tube cut ends (ID + OD edges) ahead of end-plate insertion into the 0.005" radial slip fit | [B001O62V56](https://www.amazon.com/dp/B001O62V56) | 1 | $20.38 | 112-0844221-1512225 | 2026-07-18 | 2026-07-22 | ACQUIRED |
| <!--purchase:pur-5f32a9e9bb164a428dc6bb489ccd1b8b--> JNB Pro countersink bits, 5-pc 1/4"–3/4", 82° M35 HSS 5 % cobalt, 1/4" shank — chamfer the 7/16" tap-drill holes in the 316L end-cap plates on the WEN 4208T ahead of NPT tapping | [B09C4X5R8F](https://www.amazon.com/dp/B09C4X5R8F) | 1 pk (5) | $27.78 | 112-0844221-1512225 | 2026-07-18 | 2026-07-22 | ACQUIRED |
| <!--purchase:pur-891c7eeab5084844ae5e5bd9910213e7--> 3M Scotch-Brite 7447 general-purpose hand pad, very fine, 6" × 9", aluminum oxide, 20-pack — abrasive weld-surface prep on the tube bore band and end-plate outer face | [B000LPN3WQ](https://www.amazon.com/dp/B000LPN3WQ) | 1 pk (20) | $22.95 | 112-1826837-9445804 | 2026-07-18 | 2026-07-19 | ACQUIRED |
| <!--purchase:pur-5b5c8cd276b14f3a96bf99861ccfff54--> STEPPERONLINE 1-axis CNC kit — NEMA 23 stepper, 1.9 N·m / 269 oz·in + DM542T 1.0–4.2 A, 20–50 VDC step/dir driver; cap-weld tube rotator drive | [B089Y8H8L5](https://www.amazon.com/dp/B089Y8H8L5) | 1 kit | $53.61 | 112-6362998-4945816 | 2026-08-29 | 2026-08-30 | ACQUIRED |
| <!--purchase:pur-88bf5480fde849a793acb21d07389449--> BTF-LIGHTING 24 V 4 A 96 W Class 2 power adapter, ETL listed, 5.5 × 2.1 mm DC plug + included female barrel-to-wire connector; cap-weld tube rotator supply | [B0D2XZCGL5](https://www.amazon.com/dp/B0D2XZCGL5) | 1 | $28.95 | 112-6362998-4945816 | 2026-08-29 | 2026-08-30 | ACQUIRED |
| <!--purchase:pur-e5286860c4be4e05938d36cb3e7b9c4b--> HimaPro 50122 cordless cast-aluminum deadman foot pedal, SPDT NO/NC, 15 A, IP65; rotation-enable input | [B0CYYYHL31](https://www.amazon.com/dp/B0CYYYHL31) | 1 | $39.67 | 112-8958234-5634623 | 2026-08-29 | 2026-09-01 | ACQUIRED |
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

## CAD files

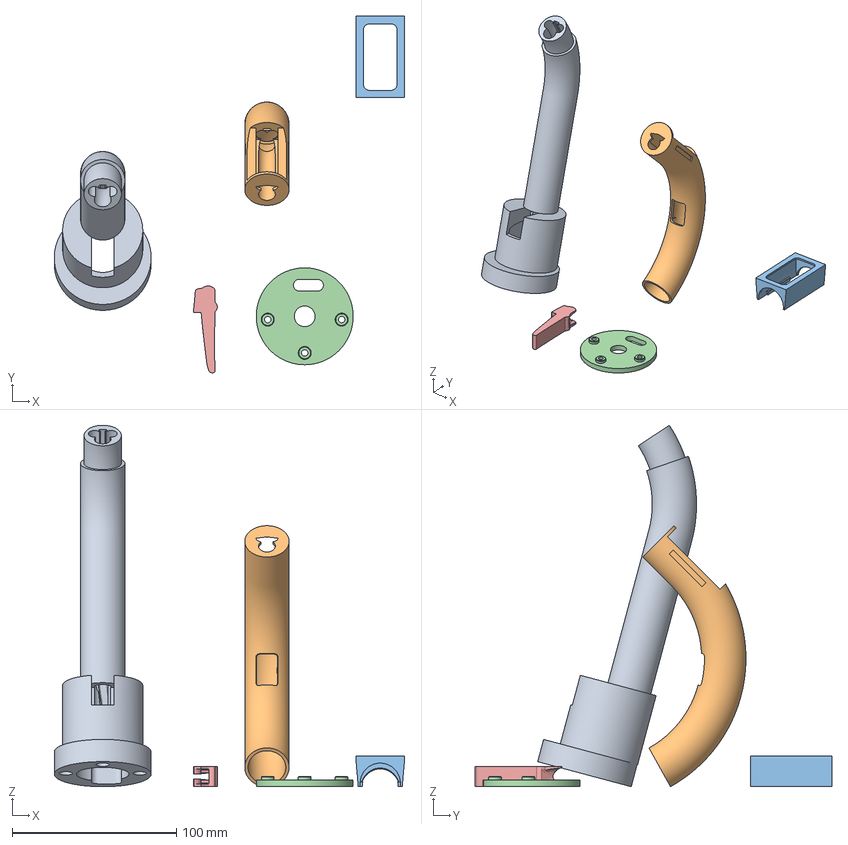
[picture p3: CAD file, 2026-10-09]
hardware/printed-parts/faucet/industrial/prints/2026-10-09-all008-solid-foot-mark2/2026-10-09-industrial-faucet-complete-all008-solid-foot-petgf-left04-z004-v3-mark2.3mf
213.4 x 217.4 x 220.1 mm
industrial-shell-base
faucet-shell-tip
industrial-display-cover
industrial-above-counter-plate
lever-replica

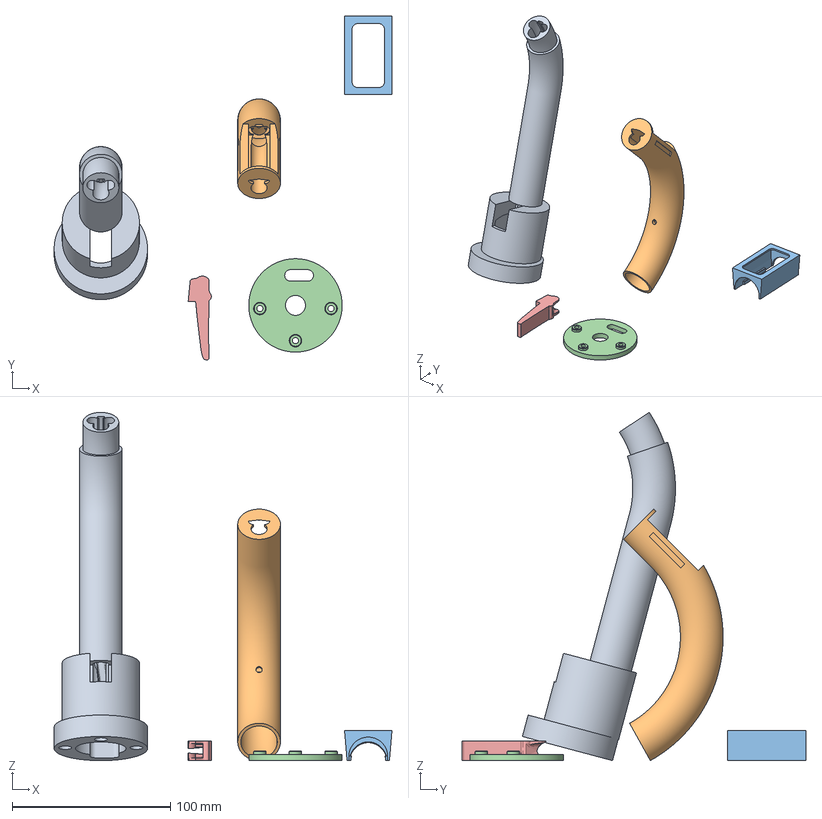
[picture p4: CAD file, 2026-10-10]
hardware/printed-parts/faucet/industrial/prints/2026-10-09-shoulders012-wing050-drip4-mark2/2026-10-09-industrial-faucet-complete-shoulders012-wing050-drip4-petgf-left04-z004-mark2.3mf
213.4 x 217.4 x 220.1 mm
industrial-shell-base
faucet-shell-tip
industrial-display-cover
industrial-above-counter-plate
lever-replica

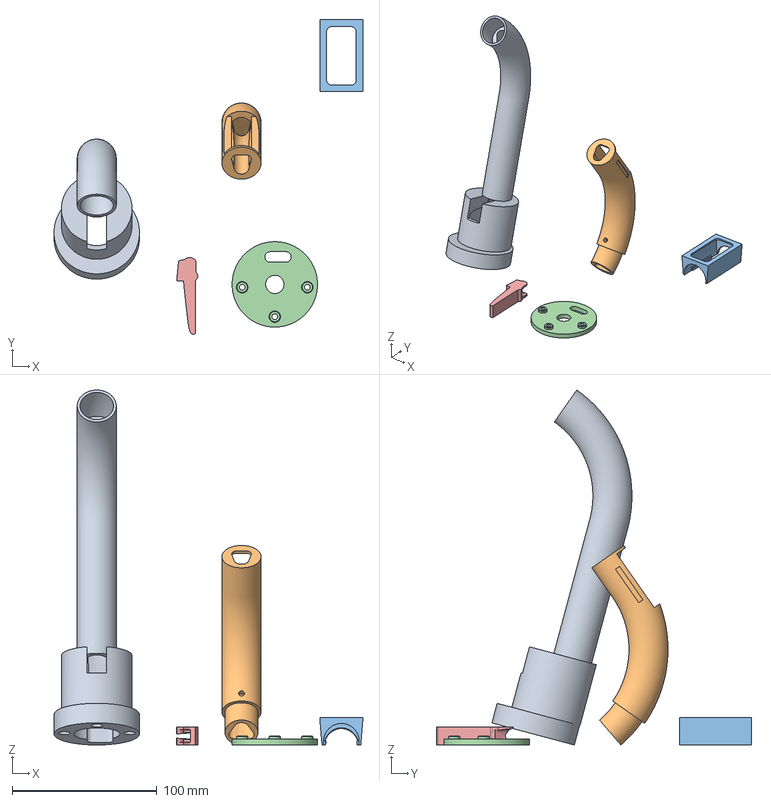
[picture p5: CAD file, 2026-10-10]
hardware/printed-parts/faucet/industrial/prints/2026-10-10-shoulders012-wing050-restored-joint-mark2/2026-10-10-industrial-faucet-complete-shoulders012-wing050-restored-joint-petgf-left04-z004-mark2.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
213.4 x 217.4 x 245.3 mm
industrial-shell-base
faucet-shell-tip
industrial-display-cover
industrial-above-counter-plate
lever-replica

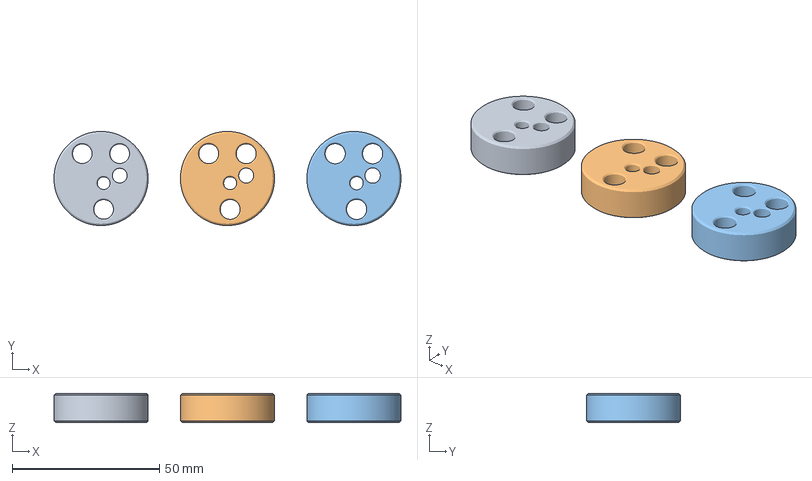
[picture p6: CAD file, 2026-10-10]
future/umbilical-organizer-exploration/diameter-increments-mark2/2026-10-09-organizer-saved-plus010-plus020-petgf-left04-z004-mark2.3mf
118.0 x 32.0 x 10.0 mm
organizer-A-q6.65-d4.30-s5.00
organizer-B-q6.75-d4.40-s5.10
organizer-C-q6.85-d4.50-s5.20

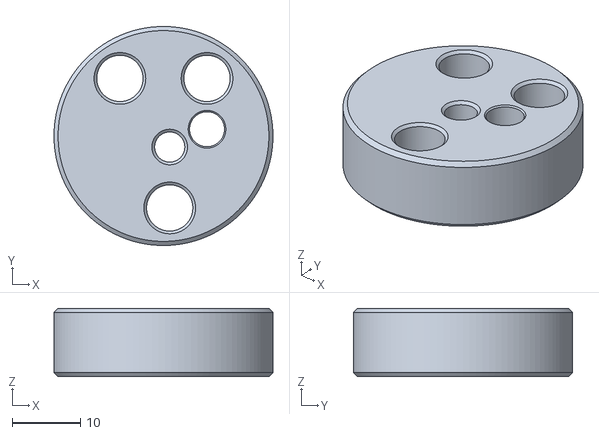
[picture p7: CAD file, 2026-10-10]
future/umbilical-organizer-exploration/diameter-increments-mark2/parts/organizer-B-q6.75-d4.40-s5.10.stl
32.0 x 32.0 x 10.0

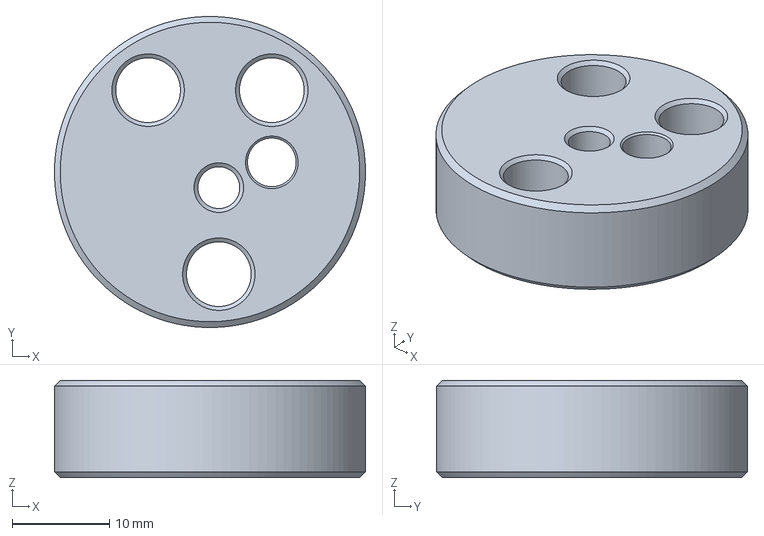
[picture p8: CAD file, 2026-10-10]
future/umbilical-organizer-exploration/drain-fit-mark2/2026-10-09-organizer-d430-petgf-left04-z004-mark2.gcode.3mf
32.0 x 32.0 x 10.0 mm

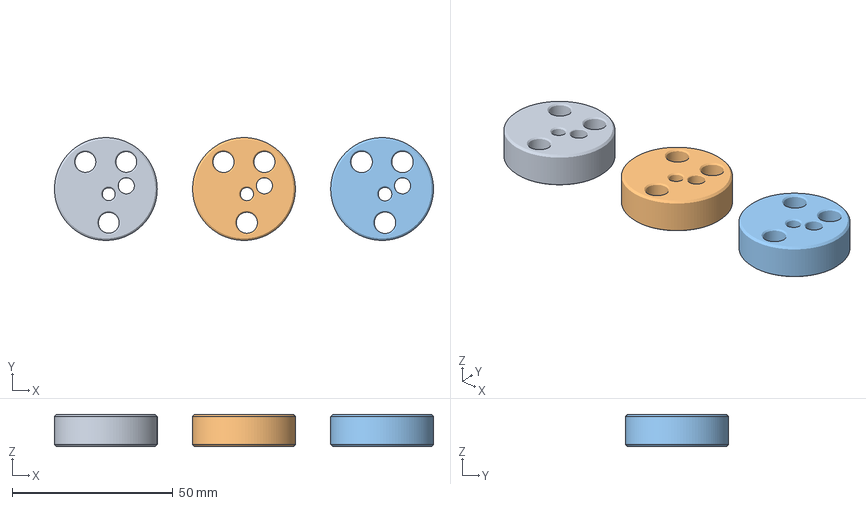
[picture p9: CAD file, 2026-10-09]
future/umbilical-organizer-exploration/fit-trial-mark2/2026-10-09-organizer-three-fits-petgf-left04-z004-mark2.3mf
118.0 x 32.0 x 10.0 mm
organizer-tight-q6.45-d4.00
organizer-best-q6.55-d4.10
organizer-loose-q6.65-d4.20

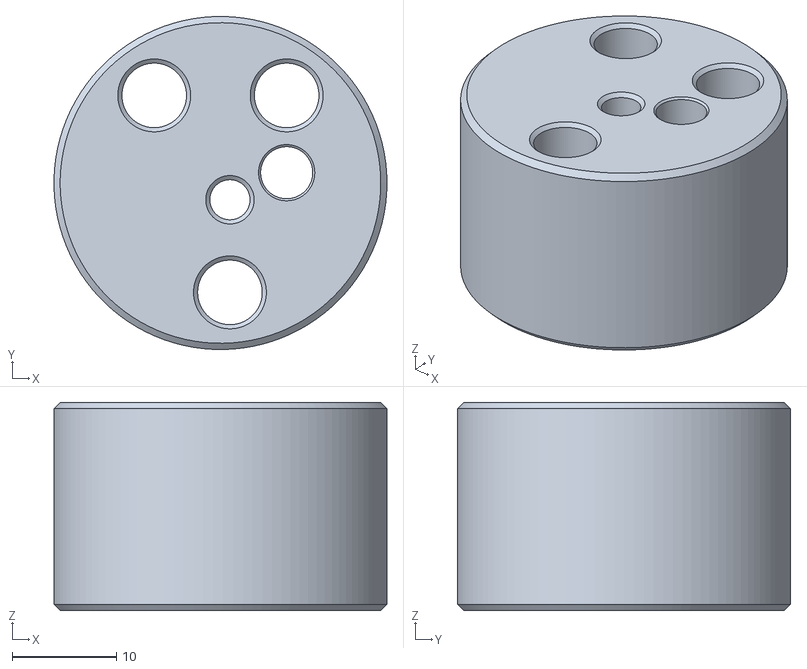
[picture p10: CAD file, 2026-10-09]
future/umbilical-organizer-exploration/organizer.stl
32.0 x 32.0 x 20.0

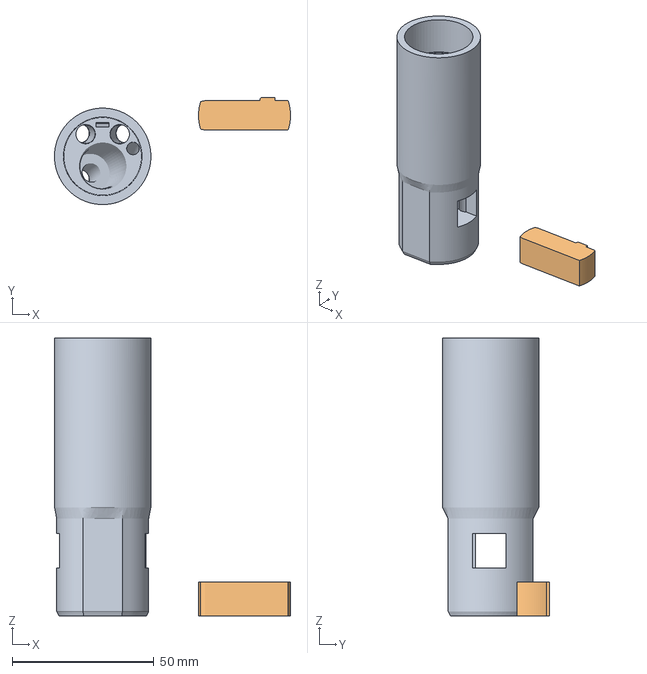
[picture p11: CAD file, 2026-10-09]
future/umbilical-plug-and-socket-exploration/guided-boot-trial/guided-boot-mark2-z004.gcode.3mf
83.2 x 37.8 x 98.0 mm
guided-boot-tactile
guided-tube-key

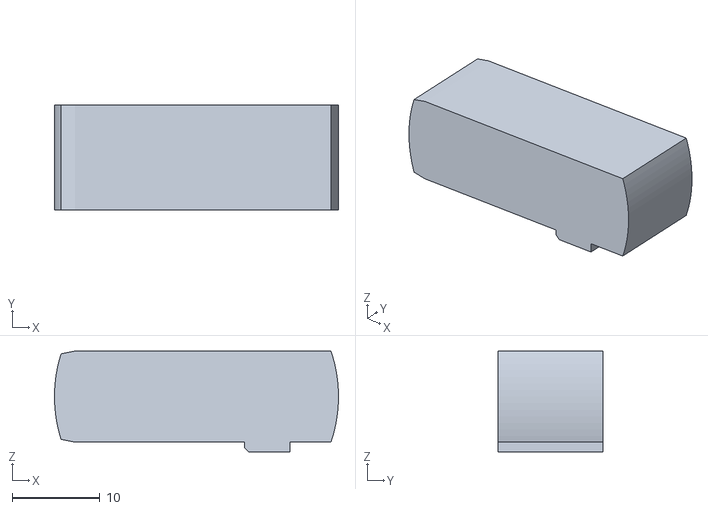
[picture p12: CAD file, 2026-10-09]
future/umbilical-plug-and-socket-exploration/guided-boot-trial/parts/guided-tube-key.stl
32.4 x 12.0 x 11.5

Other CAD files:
hardware/printed-parts/faucet/industrial/prints/2026-10-09-all008-strong-support-mark2/2026-10-09-industrial-faucet-complete-all008-strong-support-petgf-left04-z004-v4-mark2.3mf
hardware/printed-parts/faucet/industrial/prints/2026-10-09-all008-tip-grid-no-wipe-mark2/2026-10-09-industrial-faucet-complete-all008-tip-grid-no-wipe-petgf-left04-z004-v5-mark2.3mf
hardware/printed-parts/faucet/industrial/prints/2026-10-09-shoulders012-solid-foot-mark2/2026-10-09-industrial-faucet-complete-shoulders012-solid-foot-petgf-left04-z004-mark2.3mf
hardware/printed-parts/faucet/industrial/prints/2026-10-09-shoulders012-wing050-mark2/2026-10-09-industrial-faucet-complete-shoulders012-wing050-petgf-left04-z004-mark2.3mf
hardware/printed-parts/faucet/industrial/prints/2026-10-09-tip-root024-mark2/2026-10-09-industrial-faucet-complete008-tip-root024-petgf-left04-z004-v6-mark2.3mf
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

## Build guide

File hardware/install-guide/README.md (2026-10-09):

# Home Soda Machine install guide

A 9 × 7 inch landscape booklet with **32 numbered interior pages** and seven illustrated
installation steps. The 34-page reading PDF includes the front and back covers. Published
on [Drawings](https://homesodamachine.com/drawings) and at
[install-guide.pdf](https://homesodamachine.com/docs/install-guide/install-guide.pdf).

| Numbered interior pages | Content |
| --- | --- |
| 1–4 | Welcome, route, kit and cabinet space |
| 5–8 | 1. Prepare the opening and mount the faucet |
| 9–16 | 2. Add the cold-water tee: plastic tube or braided hose |
| 17–18 | 3. Match the rear connections |
| 19–21 | 4. Prepare the cylinder |
| 22–24 | 5. Water, then gas, then power |
| 25–27 | 6. Fill both flavors |
| 28–29 | 7. Chill. Choose. Pour. |
| 30–32 | Care, water connections, gas and first-pour checks |

The booklet covers installation and care. Braided-hose instructions begin on numbered page 13
(PDF page 14). Connection checks begin on numbered page 31 (PDF page 32).
The faucet has four attached tubes, including the small white 4 mm OVER tail.
Numbered pages 7–8 (PDF pages 8–9) show the seated plate from below, with a shared
rear narrow slot for both black flavor tubes, white OVER and the flat display ribbon.
The front wide slot carries the shank; the blue SODA tube connects beneath it.
The vector slot map follows the purchased steel DXF and production line positions.
Its washer and nut are omitted to expose both openings; the adjacent mounting scene
shows their assembled order.
The mounting-hole center sits at most 2 inches behind the bowl edge, with the faucet
aimed within 10 degrees of straight into the bowl and its complete drain opening exposed
above the bowl. OVER keeps its factory length and connects to its own labeled metric port.
Numbered page 3 shows every supplied kit item as a vector line drawing, with a compact
customer-supplied checklist in the sidebar. Each item sits inside a light panel with its caption
centered just beneath the drawing. A towel catches residual water at a loosened fitting.
The Fill pages show the Big Blue screen inside the machine display's frame, with its
**Start filling** control. The same screen appears on the machine in the bottle illustration.
The owner lifts the funnel cover by its front edge before the bottle goes in and presses it
back down after **Filled**. Page 30 has the funnel and both faces of its cover washed by hand.
The cabinet dimensions include the seated 3 mm funnel-cover plate.

The mounting illustrations use a nominal 30 mm countertop and approximate retained
washer and nut envelopes. Complete clamp engagement and maximum supported countertop
thickness remain open in the [mechanical concerns](../concerns.md). The 19–38 mm
geometric routing envelope measures tube and plate clearance.

## Artwork

The [On tap identity](../../brand/README.md) supplies cobalt, navy, ice and orange. Instructional
scenes use white paper, 0.72 pt slate contours (`#46515b`) and coral arrows with white outlines.
Tube and connector colors match the hardware: each bulkhead ring and tube collar is drawn in
its PET-GF spool color with its raised word. The power scene carries the white faucet mark on
its black nameplate. The glass contains dark cola and rounded ice cubes packed from the base to
just above the liquid, with a visible rim and no falling streams. The first-pour instructions
call for a glass filled with ice. The illustration comes from
`tools/install-guide/ice_scene.py`.

The concentrate bottle has a rounded PET body, tapered shoulders, an open ribbed neck, dark
liquid and a wrapped COLA concentrate label. The bottle and framed display are snapshots from
`tools/install-guide/fill_scene.py`, whose funnel and display positions follow the current
enclosure assembly. The funnel is drawn without its lift-off cover, as it stands during a fill.
`assets/fill-scene-inputs.json` records the source hashes and motion cue;
`assets/fill-screen.svg` and its PNG supply the interface. The display cover shares the
enclosure's matte black PET-GF appearance. Both Fill views use the same exposure, and the
complete frame has an uninterrupted outline.

The PDF, cover, fonts and illustration snapshots are committed here. `assets/` contains the
booklet's artwork, including its Fill-screen illustration and hose-removal scene.
`assets/print-resolution.json` registers crop and arrow coordinates against the native artwork
dimensions. The back face, rear connections and bottle scene use higher-resolution snapshots
from their registered cameras; each entry identifies its native coordinate reference by hash.
`assets/reference/` retains the native Fill views, and `assets/kit/` holds the kit SVGs.
[`kit_art.py`](../../tools/install-guide/kit_art.py) exports hidden-line views of the component
models with a common 0.68 pt pen at page size. Small machine surface details and dial lettering
are suppressed; the cord, washer, bag and booklet are illustration props.
`assets/opening-faucet-outline.svg` supplies the faucet shank and tube silhouette in the
counter-opening scene. Its dimensions and source hash register it to `opening.png`; the contour
compositor adds the component boundary where it meets the counter.
[`opening_scene.py`](../../tools/install-guide/opening_scene.py) renders the current opening,
four tube tails and display cable, then registers the component silhouette from the same pose.
Manual page composition lives in [`landscape.py`](../../tools/install-guide/landscape.py),
with the build entry point and print exporter in [`tools/install-guide/`](../../tools/install-guide/).
`_install_art.py` supplies shared CAD scene builders used by illustration tools; its output is
in `art/`.

## Compose and review

From the repository root:

```sh
tools/cad-venv/bin/python tools/install-guide/fill_scene.py --publish
tools/cad-venv/bin/python tools/install-guide/fill_scene.py --scale 2 --publish
tools/cad-venv/bin/python tools/install-guide/kit_art.py
tools/cad-venv/bin/python tools/install-guide/opening_scene.py
tools/cad-venv/bin/python tools/install-guide/build.py
tools/cad-venv/bin/python tools/install-guide/preflight.py --json hardware/install-guide/out/landscape/preflight.json
pdftoppm -scale-to 1000 -png hardware/install-guide/install-guide.pdf hardware/install-guide/out/landscape/page
```

The composer writes the reading PDF, print PDFs, thumbnail and document metadata. Copies for
ordering are in `output/pdf/`. It checks text boxes against the footer and generates page-space
contours from the saved artwork. Native illustration resolution must be at least 300 PPI at
the placed size. The preflight checks the finished PDFs' dimensions, page order,
fonts, images and reading links. `out/` holds local renders and layout measurements. Review every
rendered page at reading size before publishing.

The composer and preflight use the CAD Python environment with ReportLab, Pillow, pypdf and
pdfplumber, plus Poppler's `pdftoppm` and `pdfimages` commands.

## Print

`install-guide.pdf` is the reading copy: front cover, interiors numbered 1–32, then back cover,
all trimmed to 9 × 7 inches without bleed. PDF page labels match the printed interior numbers;
bookmarks and the route page link to each installation step.

`press/` holds the two Lulu upload files, written on each build:

| File | Size including bleed | Holds |
| --- | --- | --- |
| `press/interior.pdf` | 9.25 × 7.25 in, 32 pages | Numbered interiors 1–32, one page per PDF page |
| `press/cover.pdf` | 18.382072 × 7.25 in, one spread | Back cover left, 0.132072 in spine, front cover right |

The full-bleed interiors and outside cover have Lulu's 0.125 in bleed on every outer edge. The
cobalt ground and each page's head band extend through it. The plain cobalt spine uses Lulu's
perfect-bound formula `(32 / 444) + 0.06` inches and carries no small text. Inside covers are blank.

Lulu settings are **Print Book, Small Landscape 9 × 7, Paperback Perfect Bound, Premium Color,
80# White — Coated, Matte**, quantity **3**. Lulu uses a fixed 100# laminated paperback cover.
The 32-page count is the interior upload count; the outside cover is uploaded separately.

The interior retains embedded vector text and flattened RGB illustrations. The outside cover
is flattened at 600 PPI. An embedded sRGB profile calibrates both PDFs. Critical text is at
least 0.5 in from the trim; print files contain no links or printer marks.

[Order instructions](press/ORDER.md) identify the two upload files, configured Lulu project,
page arrangement and production-preview checks. The order bundle in `output/pdf/` includes
those instructions, both upload PDFs, the reading copy and SHA-256 checksums.

The whole booklet cannot be printed on the ET-8550: its driver offers no borderless pass with
two-sided printing, and offers two-sided printing for plain paper only.

## Installation coverage

The guide describes physical installation and the current Fill controls. It makes no
automatic-priming claim. The Prime controller path is in
`firmware/src_appliance/machine.cpp`; controller checks are documented in
[`firmware/test/README.md`](../../firmware/test/README.md).

No owner support phone number, email address or dedicated support URL is configured.

The counter page sends a stone counter to a spare 1-3/8 in sink or counter hole, or to a 1-3/8 in
diamond core bit kept wet. No stone-drilling procedure (bit speed, backing, chip control) is
verified.

The owner's regulator steps are attaching it and opening the cylinder valve: it comes set to
75 psi at the factory with the red tether already in its outlet
([`reference/taprite-3741-regulator`](../reference/taprite-3741-regulator/README.md)), and the
guide tells the owner to leave its adjusting screw alone. The owner gas checks cover locating a
leak and closing the supply. The gas disconnection procedure is not published. The cylinder nut,
the regulator's outlet push-fit and the red tether/bulkhead joint all sit upstream of the
machine's GASHER check valve, and the regulator has no outlet shutoff or manual relief. A verified
procedure must establish how the red tether is brought to zero pressure, confirmed at both gauges,
before disconnection, without touching the factory setting. Closing the cylinder alone is not a
pressure-release procedure.

The refrigerant figure is the project's documented bound, under 40 g. A per-unit charge comes
from factory run-up.

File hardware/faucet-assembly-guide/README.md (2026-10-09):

# Faucet assembly guide

[Open the display wiring on page 2](https://homesodamachine.com/read/faucet-assembly-guide/faucet-assembly-guide.pdf#page=2)
or [open the complete local PDF](faucet-assembly-guide.pdf).

18 illustrated Letter pages for building the faucet, connecting its Waveshare
ESP32-S3-Touch-LCD-1.47 display, and finishing the permanently attached
umbilical. The working pictures, short actions and check at each operation
follow the [weld-rotator guide](../weld-rotator-guide/README.md).
The complete PDF appears on the [document shelf](https://homesodamachine.com/drawings).

## Display wiring at a glance

Look directly at the **back of the PCB**, glass facing away from you, with
**USB-C at the top**. The first four pads down the **left** are the four
connections. This is a bench orientation; rotate the loose display to match.

**Installed in the faucet, USB-C points toward the dispense face.** The opposite
end points up the gooseneck. The side-section inset below and the installation
pictures on page 12 show that orientation.

Rear pad map with USB-C up on the bench; installed side section shows USB-C toward the dispense face and the opposite end up the gooseneck

All four conductors are **black**. Before separating the ribbon, add a white
index mark to **one edge at both free ends**. That edge is **C1**; count C1-C4
across the ribbon from it. These identities stay with the wires through the
vent bungs, display solder joints and wall-end plug.

| Ribbon wire | Display pad / P1 pin | RJ11 plug and jack pin | Jack's printed USOC label | Main board J3 pin / net |
| --- | --- | ---: | --- | --- |
| C1, marked edge | VBUS / P1-1, +5 V | 2 | White/orange | 3 / V5 |
| C2 | GND / P1-3, 0 V | 3 | Blue | 4 / GND |
| C3 | TXD / P1-5, GPIO43 display TX | 4 | White/blue | 2 / IO35, main RX |
| C4 | RXD / P1-7, GPIO44 display RX | 5 | Orange | 1 / IO33, main TX |

Contact-side plug orientation and the numbered RiteAV jack punchdown slots, with black wire identities and J3 destinations

**Plug:** gold contacts face you, nose up, cable down, latch on the far side.
The six positions read **1-6 left to right**. Insert **C1, C2, C3, C4 into
positions 2, 3, 4, 5**, respectively; positions 1 and 6 are empty. The C1 mark
is on the left edge in this view. Crimp a 3-prong 6P4C plug; shim the final
15 mm so its strain-relief bar grips the ribbon jacket.

**RiteAV jack:** punchdown side up, plug opening toward the bottom of the
picture. Land **J3 3/V5 in jack 2, J3 4/GND in jack 3, J3 2/IO35 in jack 4,
and J3 1/IO33 in jack 5**. The blue/orange colors belong to the jack's printed
terminal legend; the 22 AWG inboard wires are black. Punch them down with
their insulation intact, trim outward and refit the dust cover. Leave jack
terminals 1 and 6 open. J3's PCB silk reads **GND, V5, IO35, IO33** from left
to right with the component side up and J3 at the lower edge; the corresponding
physical pin numbers are **4, 3, 2, 1**.

P1 has odd pin numbers down the left and even numbers down the right. UART
is 3.3 V TTL, 921600 baud, 8N1. Leave the remaining pads open. Make the joints
with J3 and USB disconnected, after the continuously insulated display leads
have passed through both seated vent bungs. Solder only at the dry PCB ends.
Page 3 covers the joint, continuity and powered flavor-response check; page 12
covers fitting the wired display and cover without trapping the leads.

Page 2 and page 15 carry the same complete connection table. The page-3
continuity check verifies those specified connections before power is applied.

## Page map

| Pages | Work |
| --- | --- |
| 1 | Overview and linked operation map |
| 2-3 | Rear display pad map, direct solder joints, continuity and response |
| 4 | Matching Sculpted/Industrial kit and Black/White tube-cut table |
| 5-7 | Cleanup, base inserts, donor, printed lever, TPU thimble and soda tube |
| 8-10 | Individually insulated wires, pre-threaded bungs, curved pusher, drain setting |
| 11-12 | Dry neck joint, underside screws, beverage ends, wired display and cover |
| 13-14 | Gasket, captive donor washer/nut, White flavor unions and blue supply |
| 15-17 | Wall plug, foam/braid, four collars, final inspection and packing |
| 18 | Clickable sources and physical evidence scope |

For a complete build, follow pages 4-17 in order. Pages 2-3 are the electrical
reference used after the vent bungs are seated and before the display is
enclosed. The pictures are original vector schematics; the cover uses the
installation guide's committed CAD overview. The rear diagram preserves the
manufacturer's pad order. Printed picture size is not a dimension or template.

## Sources and physical scope

- [Faucet and umbilical procedure](../assembly/faucet-and-umbilical.md):
  cuts, gasket, retained hardware, supply, braid and packing.
- [Shell assembly](../printed-parts/faucet/faucet-shell/ASSEMBLY.md):
  donor and lever seating, neck/base closure, USB-C toward the dispense face,
  display motion and clearance. The shell's USB keepout and assembly's display
  placement define the installed orientation.
- [Vent-seal assembly](../printed-parts/faucet/asse-vent-seals/README.md):
  two retained bungs, continuously insulated wires, curved perimeter pusher
  and the nominal 8.0 ± 0.2 mm D setting from the tool-contact flange face.
- [Waveshare rear interface layout](https://docs.waveshare.com/ESP32-S3-Touch-LCD-1.47)
  and [P1 schematic](https://files.waveshare.com/wiki/ESP32-S3-Touch-LCD-1.47/ESP32-S3-Touch-LCD-1.47-Schematic.pdf),
  reviewed 2026-10-08: physical orientation, pad identities and pin numbers.
- [Faucet link firmware](../../firmware/src_faucet/base_link.cpp) and
  [main-board pins](../../firmware/src_appliance/pins.h): GPIO43 TX / GPIO44 RX,
  crossed to IO35 RX / IO33 TX, at 921600 baud.
- [Inboard SIG-6 wiring](../assembly/wiring.md): J3 loom through the rear jack.
- [Main-board connector implementation](../pcb/pcba/parts.tsx) and
  [J3 placement](../pcb/pcba/pcba.tsx): physical J3 pin numbers and silk order.
- [RiteAV mpn46181 jack](https://www.riteav.com/products/riteav-rj11-phone-black-punchdown-type-keystone-jack-10-pack)
  and [Leviton's six-contact USOC terminal-color table](https://leviton.com/content/dam/leviton/network-solutions/product_documents/instruction_sheet/Leviton-IST-41106-41108-Voice-Grade-Jacks.pdf):
  jack terminal identities. The SIG-6 net assignment is the table above.

The [cover acceptance](../printed-parts/faucet/faucet-display-cover/physical-acceptance.json)
and [lever acceptance](../printed-parts/faucet/lever-replica/physical-acceptance.json)
retain their identified physical articles and accepted fit/operation scope.
The guide does not establish retention force, cycle life, complete current
[vent containment](../printed-parts/faucet/vent-qualification/README.md), or the
maximum clampable countertop thickness. The 38 mm routing envelope is a
tube/cable route allowance; the actual retained washer/nut/shank stack controls
mounting engagement. Physical records remain the authority for acceptance.

## Build by hand

```sh
python3 tools/faucet-assembly-guide/build.py
```

The builder uses ReportLab, Pillow and Poppler (`pdftoppm`) with the shared
Letter furniture in `tools/assembly-guides/common.py`. It reads selected
procedure figures without importing or executing CAD. It writes:

- `hardware/faucet-assembly-guide/faucet-assembly-guide.pdf`
- `hardware/faucet-assembly-guide/faucet-assembly-guide.cover.png`
- `hardware/faucet-assembly-guide/faucet-assembly-guide.pdf.json`
- `hardware/faucet-assembly-guide/display-wiring.svg`, from the PDF's same drawing
- `hardware/faucet-assembly-guide/sig6-connector-wiring.svg`, from the page-15 drawing
- `output/pdf/faucet-assembly-guide.pdf`, the identical delivery copy
- `output/pdf/faucet-assembly-guide.sources.json`, source hashes and wiring provenance

These are committed document assets. This guide has no CAD/Bazel target,
automatic regeneration, hook or machine-build check. `render.yaml` deploys
its committed directory so the shelf can serve it. Review the affected
operation deliberately when a part, fit, procedure or pin assignment changes.
Render the resulting pages and inspect the pictures and text before publishing.

Print Letter, single-sided, color, one-up at **100% / no scaling**. The body is
already centered at 98%; the full-scale cobalt/coral bleed is separate.
The [shop-guide index](../assembly/guides/README.md#epson-letter-photo-printing)
has the Epson rear-feeder settings.

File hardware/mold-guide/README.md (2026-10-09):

# Mold operations

[Illustrated shop guide](mold-guide.pdf): 22 Letter pages for casting the silicone
funnel and filling the cold core's two caps and body with polyurethane foam.
Each page has a large picture, short bench actions and a completion check or
process gate. It uses the [weld-rotator guide](../weld-rotator-guide/README.md)'s
one-picture-per-step approach and the approved Letter sheets' print calibration.

## Operations and pages

| Page | Bench operation |
| --- | --- |
| 1 | Identify the funnel cast and three cold-core pours |
| 2 | Stage tooling, liquids, closure hardware and vacuum equipment |
| 3 | Clear bolt-pocket supports, drill infill breathers, finish forming faces and mask bare datums |
| 4 | Clean the stock 6 × 25 mm steel rod |
| 5 | Prove cure and release on the actual PETG/finish/pigment stack |
| 6 | Drop the rod into the cavity seat and lower the open core guide over it |
| 7 | Dry-close the bare parting lands with opposite flange stations |
| 8 | Apply and dry the release film |
| 9 | Measure A/B, pigment and the silicone batch |
| 10 | Degas mixed silicone with expansion room |
| 11 | Seat the rod, fill the cavity, lower the core and top up through the fill hole |
| 12 | Perform an optional equalized filled-mold vacuum cycle while fluid |
| 13 | Hold the assembled mold through room-temperature cure |
| 14 | Remove flange fasteners and open the tooling in alternating small movements |
| 15 | Pull the straight rod and trim outlet flash flush |
| 16 | Inspect and clean the funnel; check its installation |
| 17 | Stage the three 1:1 foam pours and the per-build quantity |
| 18 | Prepare and clamp the labeled top and bottom cap stacks |
| 19 | Mix each cap shot 1:1, pour, cure, trim and remove the fixture screws |
| 20 | Prove buried components, seat copper plugs and protect open paths |
| 21 | Mix the body shot 1:1 and pour it all at once through the open top |
| 22 | Trim after cure, fit reed columns/gaskets and close both caps |

The two cap pours are separate operations, with different depths and lid details.
Both use the shell's top face as their fixture. The body pour has no cap in place.
The current reservoirs are printed PETG, and the floats are printed ASA Aero.
The [silicone reservoir concept](../printed-parts/cold-core/reservoir/silicone.md)
has no production mold or casting recipe; it does not supply a bench operation
in this guide.

## Process scope

The guide is an assembly aid, not a qualification receipt. Its diagrams are
vector schematics; dimensions named in the text govern. No figure is a drill,
cut or mold-finishing template.

Funnel tooling is two printed PETG mold bodies and one straight 6 × 25 mm steel rod. The
[mold procedure](../printed-parts/zone-c/funnel-mold/README.md),
[material record](../printed-parts/zone-c/funnel-mold/silicone.md),
[tool dimensions](../printed-parts/zone-c/funnel-mold/design.json)
and [native tool check](../printed-parts/zone-c/funnel-mold/rod-check.json)
govern its dimensions and handling order. Its
[physical print record](../printed-parts/zone-c/funnel-mold/print-log.md)
retains the recorded stock-dowel and printed-shell scopes.

The rod forms a uniform 6 mm cylindrical bore. The funnel grips the 6.35 mm
drain tube over its full 5.015 mm insertion. Clean the rod and apply release
agent. The PETG shells have a separate 0.30 mm normal finishing reserve.

Set the rod in the cavity's 6.4 mm seat, resting on its floor 1.5 mm below
the block-bottom face. Lower the core over it. The core's 6.4 mm guide is open
through the dry back and has 7.7 mm of bearing length. About 4.2 mm of rod
projects above it. Both seats have 0.20 mm nominal radial clearance.
The guide annulus is open during pouring; a small amount of silicone can
emerge there. Pull the straight rod after cure and trim outlet flash flush.

The section drawings show the 6 mm silicone collar and ramp beside the solid
mold stock. A flat cavity base and steep 63.4° corbel support the flange;
the core has a flat back with a tapered circular rod-access opening.
Print with six walls, six top/bottom layers and 15% gyroid. Drill the dry-side
infill breathers in the mold procedure after printing, leaving them bare.
The core's brim-finishing pocket has 4.7 mm backing. The lower socket has at
least a 5 mm floor. The flanges are 211 × 163.683 mm,
with 16 mm of margin around the funnel brim. The diagrams omit the thin
rod-seat clearance at full-mold scale; named dimensions and the finished
reference govern.

The native mold and M4 × 20 closing hardware fit within a 247.88 mm circle
and stand 70.35 mm high. The acquired chamber's recorded interior is
299.72 mm diameter and height, leaving 25.92 mm radial clearance. Keep the
fill, vents, rod access and drilled infill breathers open during slow cycling.

The purchased BBDINO 40A material record uses a conservative five-hour demold hold
and 24-hour full-use hold at 23 C. The direct manufacturer's current page gives
30 minutes of working time and a three-hour cure at that temperature. The guide
retains the project's five-hour hold, requires the actual batch instructions
and cured witness, and supplies no unqualified heating schedule. The finished
silicone/pigment/release/post-process mixture still needs the
[wetted-surface qualification](../printed-parts/cold-core/reservoir/wetted-surface-test.md).

### Foam pours

The acquired foam is FSD B08R7TX8QJ, two-part 2 lb density closed-cell PU,
mixed 1:1 in measured shots. Each cap pours bolted mouth-up to the shell's top
face, through its lid's 20 mm hole with air leaving by the two 6 mm vents. The
body pours all at once through its open top. A build fills about 5 L of risen
foam, about 4 L of cavity plus waste, which is about 1/7 of the 1 qt kit
([BOM](../ledger/bom.md)). The [cold-core procedure](../assembly/cold-core.md)
keeps the foam data-sheet details (pot life, cure time, pour temperature window)
and the trim method as open items. The body surrounds sealed components; no foam
enters the carbonator or reservoir liquid interiors. Reed channels, top conduits,
vents and the relief outlet remain open.

## Manufacturer sources

Reviewed 2026-10-04. Batch/container instructions govern the material actually used.

- [BBDINO 40A direct product page](https://bbdino.com/products/bbdino-40a-clear-silicone-mold-making-trial-kit-gp-platinum-cure-high-hardness): equal A/B by weight or volume, required degassing, and stated room-temperature working/cure windows.
- [Smooth-On Ease Release 200](https://www.smooth-on.com/products/ease-release-200/): clean tooling, light spray from six to eight inches, ventilation and handling protection.
- [Smooth-On sealer/release reference](https://www.smooth-on.com/page/sealers-releases/): light mist/brush/mist application. Application guidance does not establish the project's BBDINO/finish-stack compatibility.
- [Smooth-On vacuum-degassing example](https://www.smooth-on.com/tutorials/making-piece-cut-block-mold/vacuum-de-gassing/): expansion headroom above the mixed batch.
- [FSD 2 lb pour foam](https://fiberglasssupplydepot.com/Expandable-Polyurethane-Pour-Foam-2lb.html): acquired material family and equal-component description.
- [FSD pour-foam SDS](https://fiberglasssupplydepot.com/pour-foam-sds): dry handling, ventilation, skin and eye protection for the liquid components.

## Manual authoring and print

This document is hand-authored and committed. It is not a machine-build step,
CAD generator, card-sync target or publication derive operation. Its shared page
furniture lives in [common.py](../../tools/assembly-guides/common.py); its
[builder](../../tools/mold-guide/build.py) reads selected small source JSON for
dimensions and hashes the reviewed sources. It imports no geometry.

Requires Python 3 with ReportLab, Pillow and pypdf, plus Poppler's `pdftoppm`
available on `PATH` for covers and page rendering.

```sh
python3 tools/mold-guide/build.py
pdftoppm -r 110 -png output/pdf/mold-guide.pdf /tmp/mold-guide-proof
```

The builder writes the delivery PDF and source receipt in `output/pdf/`, then an
identical canonical PDF, cover and catalog sidecar here. Render and inspect every
page after editing; the builder rejects action text that exceeds its allotted box.

Letter is 8.5 x 11 in. Content is centered at 98%; the cobalt top and coral right
bands extend 0.25 in beyond the page and 0.333 in inward. Print at 100% / no scaling
using the Epson rear photo feeder, Letter borderless, glossy photo media and
single-sided high-quality color. The 98% compensation is already in the file.

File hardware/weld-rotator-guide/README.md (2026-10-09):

# Weld-rotator build guide

48 pages, 8.5 × 11 in, one picture per step: print, heat-set inserts, base, bearing, drive,
nest, copper contact, controller, and six commissioning gates. Served at
[homesodamachine.com/drawings](https://homesodamachine.com/drawings) and printed one-up on
Letter.

The fixture is [`fixtures/weld-rotator/`](/hardware/printed-parts/fixtures/weld-rotator/README.md),
the rig it belongs to is [`weld-rotation-rig.md`](/hardware/assembly/weld-rotation-rig.md), and
the controller is [`src_weld_rotator/`](/firmware/src_weld_rotator/README.md). Every number here
comes from one of those three; what this document adds is the order and the pictures.

## THIS DOCUMENT IS NOT A STEP OF THE BUILD. LEAVE IT THAT WAY.

It was drawn once, by hand, and committed. No bazel target builds it, no `graph.json` entry
names it, no publish or derive lane touches it. Wiring it in would put a browser, 48 page
renders and 37 CAD renders on every publish.

What stands as it stands:

- Both scripts live under `tools/` —
  [`rotator_art.py`](/tools/weld-rotator-guide/rotator_art.py) draws the pictures,
  [`build.py`](/tools/weld-rotator-guide/build.py) binds the book. `tools/bazel/trace_inputs.py`
  names `tools/` in `ELSEWHERE`.
- Neither script keeps `note_read` / `note_write` bookkeeping.
- `web/dev-server/server.js` discovers generators under `CONTENT_ROOTS`, which is
  `[HARDWARE_DIR]`.
- `art/*.png`, `weld-rotator-guide.pdf`, its cover and its `.pdf.json` are in the git index.
  This directory is absent from `pack.py`'s `BUNDLED_ART_DIRS`; `out/` is in its
  `NOT_BUNDLED_DIRS` and in `.gitignore`.
- `render.yaml`'s `buildFilter` names this directory, so a commit here deploys the site and the
  new PDF reaches the served disk.

The guide goes stale when the fixture moves, until a person runs the two commands below.

## What is here

| | |
|---|---|
| `NN-name.html` | 48 pages, in bound order. `build.py` reads the numbers and refuses a gap. |
| `style.css` | The page system. 2550 × 3300 px = 8.5 × 11 in at 300 dpi. |
| `art/*.png` | 37 pictures, drawn from the fixture's own CadQuery by `rotator_art.py`. |
| `weld-rotator-guide.pdf` | The bound book. |
| `weld-rotator-guide.cover.png` | The cover thumbnail the drawings shelf shows. |
| `weld-rotator-guide.pdf.json` | The sidecar `web/lib/walk.js` finds the PDF through. |
| `out/` | Page renders and staged STEPs. Regenerable, gitignored, unbundled. |

## The picture conventions

Page 3 declares them to the reader; `rotator_art.py` paints them.

- **Coral** is the part or fastener the step in hand adds. Everything already standing keeps the
  stock's own black.
- **Brass** is a heat-set insert.
- **Blue** is a gauge, a probe, a packing block or the dial indicator.
- **Fasteners stand off their own holes**, along the axis they go in on.

Screws, inserts, feeler blades, blocks and the indicator are proxies built in `rotator_art.py`
to catalogue head and length. Nothing in a picture is a dimension.

## The motor screw

The fixture README and `NAMES.md` both name two **M5 × 20** countersunk screws that rise through
the carriage arms and the 23HS30-2804S's rear flange holes into **M5 square nuts** in the motor's
open corner channels. `_rotator_interface.py` states the motor's four flange holes as **Ø5.2 mm**
clearance, and `ledger/purchases.md` records the stack: 8 mm arm, 5 mm flange ear, 4 mm nut,
3 mm proud. Page 24 gives that route and says the nut's seat in the channel is recorded from the
catalogue, not from the bench.

## Rebuilding it

```bash
tools/cad-venv/bin/python tools/weld-rotator-guide/rotator_art.py   # the pictures
tools/cad-venv/bin/python tools/weld-rotator-guide/build.py         # then the book
```

`rotator_art.py` takes scene names to redraw one picture; `--list` names them all. `build.py`
renders every page through `tools/render/render-card.js`, which reports any page whose content
overflows the canvas or spills out of its `header` / `main` / `footer` band. The renderer prints
page 1 of each leaf and nothing else.

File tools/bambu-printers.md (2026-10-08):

# Bambu printers

Mark1 and Mark2 are Bambu Lab H2C printers. Their names identify the individual machines.
Mark1 retains `H2C` as its local connection key.

## Status and chamber lights

`bambu_printer.py` reads the printer names, hosts and access codes from
`~/.config/h2c-gc/run.sh`. It matches each code to its serial in Bambu Studio's saved
configuration. Credentials stay outside the repository and command output.

```sh
python3 -m venv .cache/printer-control/venv
.cache/printer-control/venv/bin/pip install -r tools/printer-requirements.txt
.cache/printer-control/venv/bin/python tools/bambu_printer.py status
.cache/printer-control/venv/bin/python tools/bambu_printer.py status H2C
.cache/printer-control/venv/bin/python tools/bambu_printer.py light Mark2 on
```

The light command takes `on` or `off`, and `--node chamber_light2` selects the second
chamber light. It verifies both the command acknowledgment and the reported light state.
Chamber illumination supports the printer's camera-based detection during a print.

## What ready looks like from software

Derek's request to start a print on a printer confirms that its bed is clear.
Proceed without a separate bed-clear question. Check the printer's current job,
material and nozzle mapping, print errors, and shared-circuit startup spacing.

`status` reports the job state and, for each machine, its two external spools and every
nozzle it knows.

- `gcode_state` is the state of the last job until the next one starts. `FINISH` and
  `FAILED` (a cancelled print) are both idle: the machine takes a job and the send dialog
  offers it. `PREPARE`, `RUNNING` and `PAUSE` are busy, and Send is disabled.
- `external_spools` are the MQTT `vir_slot` trays: `254` is the left external spool and
  `255` the right. Read both `type` and `colour` when present and verify the physical
  material from Derek's loading report. PET-GF reads PET-CF in the printer. Loading
  changes between jobs: on 2026-10-04 Mark2 carries white PET-GF on the left (`FFFFFF`)
  and blue PET-GF on the right (`46A8F9`). A slice's filament colours are the reported
  colours, because the sender compares each active nozzle's type and colour with its spool.
- `nozzles` lists every nozzle the machine knows, racked or mounted; `nozzle_type` names
  one of them, not the printing head. The send dialog checks the sliced diameter against
  the head and shows a mismatch on the filament tile.

For H2C, a `? ?` tile under **Left Nozzle** is an unresolved filament mapping. Select
the black **Ext PET-CF** tile in its popover. The numbered hotends and **R** tiles are
separate choices; their displayed diameters do not establish the left external
hotend's diameter. Check the left hotend on the printer display and the resolved
external-spool mapping. Derek's display confirms a Standard Hardened 0.4 mm left
hotend and a Standard Stainless 0.2 mm right hotend; selecting Ext PET-CF enables
the reviewed 0.4 mm cover job without a nozzle mismatch.

## Placement on unseasoned plates

Keep deposited model, support and brim beads **at least 20 mm inside the usable
bed boundary** when its outer regions have not been seasoned. Center small test
plates and aim for **80 mm** where the complete comparison fits. Choose the
inset for the part and occupied footprint; keep calibration conditions together.
Verify the emitted bead envelope, including bead width and arc extrema, before
sending. CAD containment alone does not establish adhesion.

Mark2's [edge-adhesion report](../hardware/printed-parts/enclosure/enclosure/support-bottom-gap/mark2-v2/physical-result.json)
records poor first layers near unseasoned edges. The
[centered fit trial](../hardware/printed-parts/enclosure/enclosure/magnet-retention/fit-coupons/centered-trial-v4/README.md)
uses at least 86.7 mm of full-bead edge clearance. The
[reservoir comparison placement record](../hardware/printed-parts/cold-core/reservoir/ironing-study/prints/2026-10-06-mark2/physical-result.json)
records Derek's requirement to move that complete test plate toward the center.

## Mark2 clear PETG spool order

Mark2's current AMS A load is Bambu PETG Translucent Clear (`GFG01`, transparent
`00000000`) in **A4, A3 and A1**; A2 is empty. The preferred consumption order is
**A4 → A3 → A1**, oldest to newest, as specified by Derek. Start this group on A4
and use A3 before A1 when selecting a replacement or the next spool. Use each
spool fully; remaining quantity is not a launch condition.

The AMS telemetry addresses are unit `0`, tray `3` for A4, tray `2` for A3 and
tray `0` for A1. AMS Auto-Refill is enabled. Bambu Connect's send dialog selects
the starting slot but does not display a backup sequence or priority editor.
Automatic **A4 → A3 → A1** priority is unverified; apply the preferred order when
selecting a replacement or a later job's starting slot.
The current left hotend is **0.8 mm Standard-flow**, confirmed
by Derek for the [reservoir ironing comparison](../hardware/printed-parts/cold-core/reservoir/ironing-study/README.md).

That comparison expects Mark2's **+0.04 mm user Z trim** over stock plate
compensation. Its verified native G-code clears the trim with `G29.1 Z0` and
then emits **`G29.1 Z0.02`** on textured PEI with the 0.8 mm nozzle.

## Z trim

Each printer keeps its own first-layer trim in its printer preset's start G-code. Job
names carry the requested value (`z004`, `z018`).

| printer | nozzle | requested | emitted on Textured PEI | preset on current jobs |
| --- | --- | --- | --- | --- |
| Mark2 | 0.4 mm | +0.04 mm | `G29.1 Z0.02` | `Bambu Lab H2C 0.4 Standard +0.04 Z trim` |
| Mark2 | 0.8 mm | +0.04 mm | `G29.1 Z0.02` | `Bambu Lab H2C 0.8 Standard +0.04 Z trim` |
| Mark1 (`H2C` connection key) | 0.4 mm | +0.18 mm | `G29.1 Z0.16` | `Bambu Lab H2C 0.4 Standard +0.18 Z trim` |

Mark1's standard user Z trim is +0.18 mm. A different trim requires explicit
authorization for the specific print and remains local to that print.

Bambu's Textured PEI compensation subtracts 0.02 mm from the requested trim with
the 0.4 and 0.8 mm nozzles above; other plates emit the requested value. The shared
[`petgf.3mf`](../hardware/printed-parts/petgf.3mf) working profile carries Mark2's +0.04.
A sliced archive holds `G29.1 Z0` and exactly one trim line; read that line before
sending. [z-trim.md](../hardware/printed-parts/z-trim.md) describes the mechanism.

## Recorded two-nozzle alignment

Mark2's two 0.4 mm hotends use the
[coplanar registration coupon](../hardware/printed-parts/calibration/dual-nozzle-registration/README.md)
to measure residual XY alignment. Record the exact job,
native archive, launch settings, selected X/Y indices, coordinate correction and
validation result. The correction is printer/nozzle-pair specific; keep the CAD
artwork aligned. The measurement state is in `mark2-registration.json` beside
the coupon source: the right nozzle's paths move X −0.50 mm and Y +0.70 mm (native
right `extruder_offset` `0.5x-0.7`), with the raised-artwork nameplate appearance
accepted by the user. The record's `white_correction_mm` names the spool the right
nozzle carried at measurement. The correction follows the nozzle: the
[SODA ring](../hardware/printed-parts/enclosure/tee-readiness/full-enclosure-print/native-slice-reviews/2026-10-04-bulkhead-soda-raised-mark2-v1/README.md)
applies it to blue. Residual XY error is unmeasured; the original
Y choice was tentative. Use the native
slice's verified tool-coordinate correction; keep the part geometry nominal.

The coupon uses the usual **Auto** Nozzle Offset Calibration option in Bambu
Connect, as do validation and product prints. The procedure does not depend on
touchscreen-managed high-precision calibration. A replacement hotend or changed
calibration condition requires a new alignment check.

## Power-loss recovery

On 2026-09-25 Derek reported accidentally unplugging both printers by tripping on
their power cord. H2C lost power mid-print, mid-extrusion, and recovered with no
visible defect at the interruption point. The active job was
[front-bottom, task 1279923918](../hardware/printed-parts/enclosure/tee-readiness/full-enclosure-print/native-slice-reviews/2026-09-24-enclosure-front-bottom-h2c-v7/README.md).
This is Derek's visual observation of that recovery.

## Extrusion overload after sitting loaded

Derek reports recurring extrusion overloads after the printers sit loaded and idle.
His working recovery sequence for this condition is:

1. Cut the filament at the spool side.
2. Unload through the printer's touchscreen.
3. Pull out the entire cut segment.
4. Reload from the freshly cut spool end, then resume.

The [H2C receiver trial](../hardware/printed-parts/enclosure/tee-readiness/full-enclosure-print/native-slice-reviews/2026-09-28-display-receiver-retention-h2c-v2/startup-recovery.json)
records this recovery from extrusion-motor overload 0300-801E. Moisture is Derek's
suspected cause of the recurring idle-time pattern; no moisture measurement or
controlled comparison establishes the cause. A resume is a printer start for the
shared-circuit spacing rule below.

## Purge and wipe

The [H2C purge maintenance job](h2c-purge/README.md) provides a repeatable Connect
archive for the loaded fixed left hardened 0.4 mm nozzle with black PET-GF. It
retains the native homing/material preparation and chute purge/wipe sequence,
contains no part, and ends with heater targets off. Filament-blob ejection is
physically confirmed. The blob can land on the bed: check and clear any loose,
cold blob before the next print. Consider the cycle when loaded PET-GF has been
idle for a while, before printing or another known idle period. There is no fixed
interval or measured prevention of idle-time overload. Use it only with the
documented idle-printer configuration; the package is not a general mid-print
G-code command.

## Work allocation

For one job that can run on either ready printer, prefer the one that has been
idle with suitable filament loaded longer. This compares the period spent both
idle and loaded, not idle time alone. Check material suitability first; PET-GF
is not always loaded in both printers. Use known print/load history rather than
inferring a loading time from current temperature or idle status alone.

Use both printers when Derek has them loaded, cleared and ready and the authorized
parts can be split between them with the correct materials and nozzles. Prepare
separate plates with each machine's established settings and Z trim. Derek prefers
this distribution because leaving a loaded printer idle is associated with his
reported cut-and-refeed recovery; it is not a measured diagnosis of the cause.
Keep the three-minute spacing between starts.

## Shared-circuit startup spacing

H2C and Mark2 share a circuit. Leave **at least 180 seconds between print starts**:
after the first machine accepts its job, wait three minutes before sending or resuming
the other machine. Read both machines after a power interruption; a job already running
does not need another send. Apply the spacing to recovery starts as well.

The interval is Derek's proposed trial based on his previous experience. The sender's
foreground lock serializes app access but does not enforce this interval; the operator
must wait and record both launch times.

The [2026-09-28 startup trial](../hardware/printed-parts/enclosure/tee-readiness/full-enclosure-print/native-slice-reviews/2026-09-28-shared-circuit-stagger/README.md)
records Derek's report of repeated breaker trips when both machines start close together,
including during his own manual starts. The two cover-job launch receipts are
54.421746 seconds apart; both machines subsequently report FAILED at layer 0 after
power restoration. Electrical load and the exact trip time were not measured.

## Print submission

Bambu Connect is installed at `/Applications/Bambu Connect.app`, signed in to the account
holding both printers. Its application identifier is `com.bambulab.bambu-connect`.

```sh
tools/cad-venv/bin/python tools/bambu_print.py <file.gcode.3mf> Mark2
tools/cad-venv/bin/python tools/bambu_print.py <file.gcode.3mf> Mark2 --dry-run
```

`bambu_print.py` imports a separate copy of the reviewed archive, brings Bambu Connect
forward, reads its controls and clicks them with mouse input. Its own Swift input process
is `bambu-ui/main.swift`; the command compiles it into `.cache/printer-control/` as needed.
It does not call `bambu-ax` or `bambu_send.py`. The previous application and pointer are
restored when the transaction ends. Input stops if another application takes focus.

The sender checks the archive's embedded G-code checksum, the target printer, each active
nozzle's external spool type and colour, and the standing print options. It supports one
external filament per active nozzle on a single sliced H2C plate. Spool quantity is not a
launch condition.

On a two-nozzle Mark2 plate the dialog's left tile reads `Ext PET-CF` and the right
`Ext PET-CF R`. For about a second after the dialog opens, the right tile reads
`Ext PET-CF ?` and Send is disabled while Connect reads the printer's nozzles; the
sender waits until every tile names its side. The dialog's note “Please check if the
required nozzle diameter and flow rate match the current display.” does not block Send.

`--dry-run` performs the import and dialog checks, then cancels without clicking Send. It
also runs while a printer is busy, when Send is disabled. An ordinary run refuses a busy
printer before opening the application. A Send click is made only once per dialog.

Success requires a new printer job ID, the archive's name, and PREPARE or RUNNING with no
print error. The MQTT connection stays open throughout the transaction. A fresh-dialog
retry is allowed only when no command reply, upload or new job was observed, the printer
is still idle on its original job, and the app shows no transfer. Errors and ambiguous
results stop the sender. Up to three attempts are made; `--attempts 1` selects one.
The acceptance wait samples Connect's visible text for short-lived request and upload
errors, including “Resource does not exist,” and stops without a repeat send when one
appears.

Successful launches write `.cache/printer-control/<printer>-<job-id>-launch.json`, including
the original archive and G-code hashes. Bambu Connect's imported copy is separate because
the application can rewrite the file it imports.

### Bambu Studio send from an existing slice

`bambu_print_archive.py source.gcode.3mf output.gcode.3mf` creates a separate
print-only archive. It removes editable geometry and its model references while
preserving every G-code byte, checksum, preview, slice metadata and print setting.
The source stays intact. Open the output with Bambu Studio's **Open Project**;
it opens in Preview with **Print plate** enabled. Do not reslice it.

Choose the target printer and external-spool mapping, and explicitly verify
Timelapse On, Bed Leveling On, Flow Calibration Auto and Nozzle Offset Calibration
Auto in Studio's own send dialog. The accepted printer name can come from the
plate name rather than the archive filename. Record that reported name, the new
task ID, the submitted archive hash and the unchanged G-code hash. The
[Mark2 back-bottom launch](../hardware/printed-parts/enclosure/bottom-grip-print/mark2/launch.json)
records an accepted Studio send with LAN acceleration using this packaging.

### Background accessibility sender

```sh
.cache/printer-control/venv/bin/python tools/bambu_send.py <file.gcode.3mf> H2C
.cache/printer-control/venv/bin/python tools/bambu_send.py <file.gcode.3mf> Mark2 --dry-run
```

`bambu_send.py` performs the procedure below and reads each step back before the next.
When Bambu Connect is not running it starts it with `open -g` and waits for its window.
`--dry-run` stops at the Send button and cancels the dialog. `--timelapse Off` departs
from the standing options. It exits non-zero, with the dialog cancelled, on any reading
that is not the one expected, and it ends with the printer's own MQTT report of the job.

`bambu-ax` drives Bambu Connect in place, leaving the screen to whatever is using it.
Bambu Connect is an Electron application: setting `AXManualAccessibility` on it exposes
the Chromium accessibility tree, and `AXUIElementPerformAction` presses a control where
it stands. The window never comes forward, and the file chooser — an `AXSheet` on the
main window — is driven the same way, by selecting a row and pressing **Open**. No
keystroke is involved.

```sh
tools/bambu-ax/build.sh                     # once, writes the binary beside the script
tools/bambu-ax/bambu-ax state               # every static text on the current page
tools/bambu-ax/bambu-ax import <file.gcode.3mf>
tools/bambu-ax/bambu-ax tree                # every labelled or actionable element
tools/bambu-ax/bambu-ax press "Print" --role AXButton
tools/bambu-ax/bambu-ax click <x> <y> [x y ...]
```

`press`, `act` and `value` take a label substring or a `#n` from `tree`, narrowed with
`--role` and `--nth`. Each one reports whether the frontmost application changed, so a step
that costs the screen says so. Accessibility trust comes from the calling process.

### The procedure

1. **Open the target's device page.** `press "Devices" --role AXLink`, then
   `press "<name>" --role AXLink`. The send dialog offers, as its printer, the machine
   whose device page was opened last while that machine was idle.
2. **Import.** `import <file.gcode.3mf>` opens the Print tab, walks the chooser to the
   file and opens it. `state` then reads the summary: compatible printer, bed type,
   filament, nozzle diameter, time and weight. A path through a hidden directory is
   staged as a visible copy first, and a path inside the working tree walks fastest.
3. **Open the dialog.** `press "Print" --role AXButton`. In `tree`, the group labelled
   `<name> chevron_down` is the printer offered. When it is not the target, the selector's
   popover chooses it: `click <x+70> <y+32> <x+81> <y+91+36n>` from the selector's `@x,y`,
   its name text and then row `n` of the popover, the printers in `PRINTERS` order, in one
   call. One call is the point: an AXPress opens the popover too, but the front borrow
   of the click that follows closes it, so the row click lands on the dialog. The
   popover is not in the tree; the selector afterwards is, and it must read the target
   before anything else is pressed. The borrow holds the front for a second or two, and a
   keystroke typed elsewhere in that window takes the popover with it, so the two clicks
   are retried, up to three times, until the selector reads the target. The device page
   opened in step 1 does not decide it:
   on 2026-09-20 the dialog offered H2C three times after Mark2's page was opened and
   settled.
4. **Read the filament tile.** The `AXGroup` under `Left Nozzle` reads the selected
   AMS slot (for example `A4 PETG`) or the external source (`Ext PET-CF`). A `? ?`
   tile requires mapping to the intended source. For an external spool it is one call:
   `click <x+47> <y+30> <x-245> <y+282>` from the tile's `@x,y` — its centre, then the
   External spool tile in the popover that opens under it. The popover is not in the
   tree; the tile afterwards is, and it must read `Ext PET-CF`. The offsets are H2C's
   popover: one AMS unit's trays above the External spool. If another app takes a
   keystroke during the click, the popover can close before the External click lands.
   The sender reads the tile after each attempt and, on a miss, closes the dialog
   and reopens a fresh one before retrying. The tile toggles the popover, so another
   click in the same dialog is not a safe retry.
5. **Read the print options.** Each option is a row of `AXRadioButton`s and the chosen
   one carries an `AXImage "radio"` as its first child in `tree`. The standing settings
   are Timelapse On, Auto bed leveling On, Flow dynamic calibration Auto and Nozzle
   Offset Calibration Auto; the dialog remembers the last send. `press "#n" --expect On`
   changes one.
6. **Send.** `press "confirm" --role AXButton` — the button is labelled `confirm`. It is
   disabled until the dialog has finished loading the printer, while the tile reads
   `? ?`, and while the target is busy; `tree` and `find` mark a disabled control
   `(disabled)`, and an `AXPress` on one does nothing. The dialog closes when the
   application has taken the job, so a dialog still open after the press is a press
   that did not land.
7. **Verify with the printer.** `bambu_printer.py status <name>` reports `PREPARE` within
   seconds and then `RUNNING` with the archive's name as `subtask_name`. A 47 MB archive
   took under ten seconds to land. Record the reading with the job.

   The dialog can close and no job arrive: the job id does not move, the printer's
   `upload` block stays idle, and nothing lands late. This happened to three Mark2 sends
   (twice on 2026-09-22, once on 2026-09-23) with the file, printer and procedure the same
   as sends that landed. `bambu_send.py` presses Send once per dialog and holds the
   printer's report topic open across it, printing any command reply (`project_file` with
   its result and reason), upload, error or HMS it hears, and the application's page text at
   the close, a second later and five seconds later. A send that has not landed is watched a
   further pause, and longer while the page reads Sending, Uploading or Downloading. Only then
   is it made again from a fresh dialog, up to three rounds, and only while the printer reads
   the job id it had before the first send, idle, with no upload and no new error or HMS. A
   command the printer answered is not sent again.

### What the application will not show

The printer selector's popup and the AMS filament-mapping popover are drawn outside the
accessibility tree: `find` returns nothing with either open, and an `AXPress` on their
`AXGroup` divs is a no-op, because Chromium synthesizes a click only for button and link
roles. An event sent with `postToPid` never arrives either. The global tap is the only
delivery and it follows the frontmost application, so `click` brings the window forward,
clicks every coordinate given, then restores both the previous application and the
pointer. One borrow measures about a second; both coordinates go in one call, and the
popover under the tile survives the 0.25 s between them. A popover's only reading is
the control it changes.

Changing the printer in the selector clears the filament mapping.

`#n` indices renumber whenever the tree changes, so `press` and `act` refuse a bare `#n`
and require `--expect <label or role>`, checked against the element found there. A number
carried over from an earlier dump then reports what now holds it instead of pressing it.
Matching by label, narrowed with `--role`, needs no `--expect`. A label match is a
substring match: `press "Print" --role AXLink` also matches `My Printers`, so pass
`--nth 0` on a device page.

A chooser acts on its selection, not on a click. `AXOpen` on the row's cell is refused
with -25205, `AXConfirm` reports success and does nothing, and a click lands without the
panel taking it; setting `AXSelected` on the row's `AXRow` and pressing **Open** works with
the application in the background. A sidebar row is the exception — it navigates on
`AXOpen`, and that action sits on its `AXCell`, not on the `AXStaticText` holding the name.
`select "<row name>"` chooses a row in a chooser that is already open.

Synthesized keyboard input cannot reach the application at all. `CGEvent` delivery to
`.cghidEventTap` follows the frontmost application, so a keystroke needs the window in
front and takes the screen for every step after it. `open -g -j -a 'Bambu Connect'`
starts the application without the screen if it is not already running.

Two sessions in the application at once cancel each other's dialogs.

The signed printer-control application handles protected operations. Bambu's network
library checks the calling application's signature for those operations; loading the
library in a standalone helper does not provide print-start authorization
([Bambu authorization controls](https://blog.bambulab.com/firmware-update-introducing-new-authorization-control-system-2/)).
The printer ignores MQTT `stop` from an unsigned client.

The `.gcode.3mf` carries the sliced machine G-code, including the printer's
[Z trim](#z-trim). The
enclosure jobs' profiles, offsets and file hashes are recorded in
`hardware/printed-parts/enclosure/enclosure/print-jobs.json`, and the lever's in
`hardware/printed-parts/faucet/lever-replica/print-jobs.json`.

A print sent while the printer is loading filament or purging, which is a nozzle or bed
target above zero with no job, starts nothing and says nothing: the dialog closes, the
printer stays on its last state, and its `job_id` does not move. `bambu_send.py` reads the
targets before it sends and waits for them to fall, and when a send is dropped anyway it
reads them again and makes the whole pass again, up to three times. The job id moving is
what says a job reached the printer; the file name alone cannot, because the last job can
carry the same one.

Right after a filament load from the touchscreen, a send can instead be refused outright.
The printer answers `project_file` with `ERROR STATE`, err_code 84033549 (0502400D,
"Failed to start a new task: filament loading/unloading not completed"). Its nozzle and
bed targets already read zero while the loaded nozzle is still hot. The same archive is
accepted once that nozzle has cooled
([CO2 ring](../hardware/printed-parts/enclosure/tee-readiness/full-enclosure-print/native-slice-reviews/2026-10-04-bulkhead-co2-raised-mark2-v1/rejected-send.json)).
`ams_status` 0x300 and an extruder `stat` with 0x0300 set also appear while a printer
prints normally, so neither marks an open load.

## Printer storage

The existing `h2c_timelapse_gc.py` connects to the LAN FTPS service. Its listing, archive
and retention commands are described in [h2c-timelapse-gc.md](h2c-timelapse-gc.md).

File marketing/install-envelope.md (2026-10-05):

# Install envelope

The space the soda machine installs into: a standard kitchen sink base cabinet, already
occupied. This is the physical bound on the enclosure's silhouette. The cabinet belongs to the
customer and does not change with which machine goes into it, so it is stated once, here.

Who that customer is, is in [`target-market.md`](/marketing/target-market.md); what they do
on install day is in [`unboxing-and-installation.md`](/marketing/unboxing-and-installation.md).

## The cabinet

US kitchen sink base cabinets are standard stock: **34.5" high × 24" deep**, in widths of
**30", 33" and 36"** (24", 27", 39" and 42" are catalogued). Every major line — Hampton Bay,
Thomasville, Diamond, the RTA houses — ships those three numbers.

Interior clear height is **[755.7 mm](CABINET_CLEAR_H)**: the 34.5" carcass less the 4" toe
kick less the 3/4" deck. That derivation is the one the umbilical's length stack-up already runs on
([`/hardware/assembly/faucet-and-umbilical.md`](/hardware/assembly/faucet-and-umbilical.md)
§1), and it is the cabinet number the machine's own geometry is sized against.

## What is already in it

The cabinet is not empty, and its occupants take a **column out of the middle** rather than a
slice off one side:

| Occupant | Size | Where it sits |
|---|---|---|
| Garbage disposal | Ø 210–254 mm, 311–413 mm tall | bolted under the sink flange, hanging into the middle of the cabinet |
| P-trap + drain arm | — | behind and above the disposal's foot |
| Angle stops + supply lines | — | back wall or floor, to one side |
| CO2 cylinder, 5 lb | Ø 133 × 457 mm, plus regulator | on the cabinet floor beside the machine |

The disposal is the largest of them and the one that shapes what is left. InSinkErator's
Evolution line is [8.25" wide × 12.25" tall](https://www.insinkerator.com) at the .75 and
1 HP sizes and 10" diameter × 16.25" tall for Cover Control Plus. It is fastened to the sink
and does not move.

**What is left is a slot beside it** — narrow across the cabinet, and as deep and as tall as
the cabinet is. Height and depth are uncontested there. Width is the constraint.

The CO2 cylinder stands in that same slot. It is customer-supplied (5 lb, per
[`/hardware/ledger/bom.md`](/hardware/ledger/bom.md) "External"), stands beside the machine
on a short tether to the inlet in the +Y wall of back-top
([`y-wall-of-back-top/README.md`](/hardware/printed-parts/enclosure/y-wall-of-back-top/README.md)
"Connections inventory"), and is Ø 133 × 457 mm before its CGA-320 regulator. Machine width
plus 133 mm plus a working gap is what the pair asks of the slot.

## What the machine needs beyond its own box

- **[60 mm](TURN_IN) behind the rear face** — lead, 90° bend at R12, and collet. The collet
  stands [9.5 mm](COLLET_PROUD) proud of the wall's own outer face, and the bulkhead ring it
  bears on lies flush in that face — the pocket is cut to the ring's own
  [2 mm](BULKHEAD_RING_THICK), so the ring buys the tube nothing
  (`faucet-and-umbilical.md` §1, `printed-parts/enclosure/bulkhead-ring/`).
- **300 mm of pull-forward** — the umbilical's service loop, sized to bring the +Y wall of
  back-top to the cabinet face so its own connections can be reached.
- **[74.27 mm](CART_DRAW) of draw at the FRONT face** — the pump cartridge comes straight
  out of the bay with both peristaltic pumps and their tubing aboard, and that figure is its
  own depth, exterior face to the aft face that stops on the collet plate. A hand on the
  face and somewhere to set it down are on top of it. This is the one service access that
  faces the room rather than a wall
  ([`service/pump-replacement.md`](/hardware/service/pump-replacement.md)).
  **It is a draw, not a standing clearance.** The pull-forward above is what answers it: the
  machine comes out to the cabinet face on the day the cartridge is wanted, so the floor in
  front of it is the cabinet's to use the rest of the time.
- **40 mm at each side face** — the condenser draws through the grille on one side and
  exhausts through the other, and this is the gap that keeps the cabinet from being the
  restriction. The loop rejects the evaporator's duty plus the compressor's work, both of them
  ~90–120 W class ([`reference/ice-maker/`](/hardware/reference/ice-maker/README.md),
  [`reference/compressor/`](/hardware/reference/compressor/README.md)), so ~240 W at worst. Carried
  on a 10 K rise that is 21 L/s, and holding the approach velocity in the side slot to 1.5 m/s —
  where the dynamic head is 1.3 Pa against a finstack's tens — asks 138 cm² of slot. Fed from the
  front and the back over the box's own 361 mm, that is 19 mm, and 40 doubles it for dust, for a
  cabinet that is never as clear as a drawing, and for an approach that is never even. It fits the
  30" cabinet with the cylinder still beside it.
- **Headroom over the top wall** — the funnel is filled by inverting a 440 mL
  concentrate bottle over it
  ([`zone-c/README.md`](/hardware/printed-parts/zone-c/README.md)).

## The machine against it

The machine's own silhouette is stated where it is cut, on the box that sets it:
[`enclosure/README.md`](/hardware/printed-parts/enclosure/enclosure/README.md), and the
procedure that builds those walls,
[`assembly/enclosure-mechanical.md`](/hardware/assembly/enclosure-mechanical.md) §1. Both are
written by the run that places the pack, so both move the day the box does. No third copy is
kept here: what this page owes the cabinet is the clearance list above, which is about the
room around the machine rather than the machine.

## What comparable devices measure

Appliances that install in this cabinet, or that carry the same subsystems:

| Device | W × D × H (mm) | W : D : H | Contents |
|---|---|---|---|
| [Brio Q60](https://briowt.com/products/brio-q60-4-stage-ro-sparkling-countertop-water-dispenser) | 220 × 467 × 430 | 1 : 2.12 : 1.95 | RO, compressor chiller, carbonator, CO2 cylinder, hot tank |
| [Quooker CUBE](https://www.quooker.co.uk) | 223 × 340 × 500 | 1 : 1.52 : 2.24 | carbonator + chiller, under-sink |
| [Waterdrop G3P800](https://www.homedepot.com) | 144–159 × 462 × 425–450 | 1 : ~3.1 : ~3.0 | tankless RO |
| [APEC ROES-50](https://www.apecwater.com/products/roes-50) | rack 133 × 406 × 445, tank Ø 279 × 381 | 1 : 3.05 : 3.35 | tanked RO |
| [Quooker COMBI+](https://www.quooker.co.uk) | Ø 200 × 530 | cylinder | hot tank |
| [InSinkErator HWT-F1000S](https://www.insinkerator.com) | 156 × 171 × 276 | 1 : 1.10 : 1.77 | 2/3 gal hot tank |

Every one of them is narrow. The width band is **133–223 mm**, and it holds across devices
whose insides have nothing in common — a cartridge rack, a hot tank, a
compressor-and-carbonator. Depth and height range over more than a factor of two in the same
set. Width is the dimension the category agrees on.

Brio's Q60 carries the same subsystems this machine does — compressor chiller, carbonator,
CO2 cylinder, filtration, dispense — in 220 × 467 × 430 mm on a 0.103 m² footprint. It is a
countertop unit, so it never had to clear a trap, and it is narrow anyway.

The same band shows up in this machine's own parts. The two largest solids in the machine
— the [foam shell](/hardware/printed-parts/cold-core/foam-shell/README.md) across its short
axis, and the mated [compressor](/hardware/reference/compressor/README.md) and
[condenser](/hardware/reference/condenser-block/README.md) across theirs — are within a few
millimetres of each other, and the thin edition's width is built
on the first of them
([`enclosure/README.md`](/hardware/printed-parts/enclosure/README.md)).

## Sources
[value](NAME) texts are updated by:
- `/marketing/_install_envelope_sync.py`

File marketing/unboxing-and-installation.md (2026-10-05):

# Unboxing and the install guide

The **install guide** is a bound 9 × 7 inch landscape booklet with 32 numbered interior pages.
It sits face up on the documentation face of the install kit, above the welcome letter.
Its illustrated kit page shows each supplied item, with the customer-supplied preparation
checklist beside it. Packing placement is in
[`finish-pack-ship.md`](/hardware/assembly/finish-pack-ship.md).

## Installation

The guide follows seven steps:

1. Mount the faucet.
2. Add the cold-water tee.
3. Match the rear connections.
4. Prepare the cylinder.
5. Water, then gas, then power.
6. Fill both flavors.
7. Chill. Choose. Pour.

Both the plastic-tube and braided-hose water connections have illustrated instructions.
The filtered run ships assembled; lay the filter flat and leave the long tubes in easy curves.
The booklet also covers the countertop opening, cabinet space, care and connection checks.
The water-connection supplies include a towel and the applicable wrenches.

The guide is published on [Drawings](https://homesodamachine.com/drawings), with its download at
[install-guide.pdf](https://homesodamachine.com/docs/install-guide/install-guide.pdf).
Its source and print instructions are in
[`hardware/install-guide/`](/hardware/install-guide/README.md).

The [On tap identity](/brand/README.md) supplies cobalt, navy, ice and orange.
Instructional scenes use slate contours, and tube and connector colors match the hardware.
Kit inventory uses consistent vector line drawings. Artwork, fonts and the finished PDF
are committed beside the guide.

The cold kit keeps its own guide in its own bag
([`bom.md`](/hardware/ledger/bom.md) §14). Its tube cutter and insulation are for
optional cold-line work after installation.

## Print review

Order through Lulu: **Small Landscape 9 × 7, Paperback Perfect Bound, Premium Color,
80# White — Coated, Matte**, quantity **3**. Upload the separate
`hardware/install-guide/press/interior.pdf` and `hardware/install-guide/press/cover.pdf` files.
[ORDER.md](/hardware/install-guide/press/ORDER.md) supplies the upload and preview checks.
Review the proof at actual size, with particular attention to the kit outlines, gutter,
connection arrows and the two water paths.

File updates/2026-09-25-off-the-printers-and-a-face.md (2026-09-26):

---
title: The machine comes off the printers, and gets a face
start: 2026-08-26
end: 2026-09-25
kind: period
image: /update-images/2026-09-25-nameplate.png
image_alt: The first printed nameplate: the new faucet mark, HOME SODA MACHINE, and a QR code for the unit's own page.
lede: Three of the four enclosure quadrants, the faucet shell, the pump cartridge and the nameplate came off the printers in glass-filled PET, the project got a new mark, and two films went up.
---

For most of this project the machine has lived in CAD. This month most of what a buyer would see of it came off two Bambu H2C printers, in black and white glass-filled PET. Nothing printed has held water or gas yet; that, and the cold, are still ahead.

## The box, in print

The enclosure is four printed quadrants around the cold core, about 8-1/2 in wide, 18-3/8 in deep and 14-1/4 in tall. Three of the four were printed between 21 and 23 September, all in black PET-GF: front-top, front-bottom, and back-top, which prints upside down on its own roof. Back-bottom is sliced and waiting. Front-top and front-bottom went back on the plate on the 24th, and one of those reprints rode through a power cut on the 25th and picked up again without a visible mark.

Back-top's roof is a single slab of the part itself: its outer face is the first layer on the plate and everything inside stands up off it, which is why the separate ceiling panel it used to carry is gone. Every face that points down is held by a column to that slab, a full-width 45° ledge, or a support that peels away cleanly, and nothing is thinner than about an eighth of an inch.

Front-top changed shape on 19 September. The flat 45° face the machine display sat on became a sweep — a curve off the front wall, a 30° plane for the display, a curve onto the roof — and curves like these now print in fine layers all the way through, so they come off smooth rather than stepped. The display sits under a flush cover that snaps in with no screws. The first cover bowed about 0.16 in once its snaps engaged; four trial prints since have moved the snaps inward, and the bow is now slight, though the cover does not yet stay put. Each side wall has a handhold at the floor, and the box closes with six screws.

The printed front-top on 24 September, in black PET-GF with its fluted skin. The screen is the machine display, under the first snap-in cover, which lifts along its long edge.

## The faucet, the pumps and the tees

The faucet shell — the printed cover that wraps the bought faucet and its flavor tubes — comes in two styles, Sculpted and Industrial, which share a tip, a joint and their mounts, each in black or white. The white Sculpted shell printed on 18 September as one plate of four parts in about four and a half hours, and black Industrial and Sculpted shells went on the printer the next two nights. The faucet display's cover springs onto the tip with no fasteners, and a printed copy of the faucet's own lever, rebuilt from a 3D scan, passed on the 20th.

Sculpted and Industrial, in black and white: a frame from the One Less Errand film, drawn from the faucets' own models.

The two flavor pumps now slide out of the front as one pump cartridge, without taking a quadrant off the box. Pulling it presses all four tube collets on the way out, and its cord unplugs at a jack. An earlier print held both pumps with no play, and the whole cartridge printed on 21 September; connecting and releasing the tubes through it is the next test. The pumps themselves are now Kamoer KPHM600s, since the KPHM400 stopped being available.

The part that holds the four tees beside the pumps went the other way. A spring tray, a two-piece carrier with squeeze grips and a stiffened web were all deleted on 22 September for a clean start, and the same evening it came back as one plate: a strip of PET-GF through both front flanks, with the four tees tied to it and four springs pushing it back. Pulling the pump cartridge draws it forward just far enough to press every tee's collet. It printed on the 24th; its rounded lower edges curled, and the latest print is good enough to carry on with.

## Carbonation, and the funnel

The carbonator changed how it carbonates. Water now comes in through a 1/16-inch hole in a stainless cap on the top inlet and sprays through the CO2 above the water line, and the stone that bubbled gas up through the water is gone. The diaphragm pump that feeds it is now a G Ganen, rated to 110 PSI; the old pump's published curve ran out of flow at 100. The jet's parts arrived on 17 September but it has not been made yet, and the new pump has been scanned but not run.

Two days after the last entry, the funnel's two bench documents came off the drawings shelf. On 19 September the funnel itself grew to 20.3 fl oz, with its outlet centered. The mold for that funnel is sliced but not printed, and nothing has been cast yet.

## A face

On 15 September the project got a new mark: a pale faucet with an orange drop, on cobalt blue. It replaced the pink glass on dark navy, and it is now wherever the machine shows itself — this site, the app icons, the guide covers, the YouTube channel, the boot animation on the machine display, and the nameplate.

The first nameplate, printed face-down in black and white PET-GF on 20 September.

The nameplate carries the mark, the name and a QR code for HOSM.US/0001, short enough for the smallest QR code there is. It scans cleanly from 2 ft. That address opens [the unit's own page](https://homesodamachine.com/0001), with a get-started checklist and the install's seven steps, each linked to its page in the install guide.

The machine display wears the new colors too. Its home screen, On tap, shows the selected flavor's level, with its pour ratio a tap away and adjustable from 1:6 to 1:24, and Settings opens on a side view of the machine with its ten reed switches reading live. Each flavor can wear one of eight pictures on the machine display and the faucet — four built in and four of the owner's own, cropped on a phone to the shape of the faucet's glass.

The machine display's Fill page in the new colors, as the install guide draws it.

## On the bench

The phone app can now update every board in the machine: from an iPhone over Bluetooth to the faucet display, then by wire to the main board and on to the machine display. It worked end to end on the bench boards, and between 17 and 21 September it was made dependable. It offers only a build newer than the one installed, a single lost frame costs well under a second instead of stalling the update, and it reports done only after reading the new versions back.

The main board now runs the machine's jobs: filling a flavor, cleaning, drying before a pump swap, the pour itself with pump speed following the flow meter, a self-test, and the cold loop that holds the carbonator between about 36 and 39 °F with a freeze cutout. All of it has been walked through on the bench with simulated readings. None of it has run with water, a temperature probe or the compressor.

## For the buyer

The install guide is now a printed book: 24 saddle-stitched pages, 6-5/8 × 10-1/4 in, in the new colors, walking the same seven numbered steps as a single quick-start sheet. Three copies were ordered on 16 September and have not arrived. The install cuts no tubing, and it hands no step to anyone else: the buyer fits the CO2 regulator to the cylinder and checks it by ear and with soapy water. The regulator's tube ends in gray, CO2-rated fittings that go on by hand.

## The shop

The weld rotator is built: a printed turntable that stands the 5-inch stainless carbonator tube upright and turns it under the hand-held laser welder for as long as a foot pedal is held down. It went together on the welding table on 11 and 12 September and turns under the pedal; nothing has been welded on it yet. Its 48-page build guide is on [the drawings shelf](/drawings).

A 3D scanner arrived on 18 September. In ten sessions since, it has measured most of the bought parts the machine is built around — the tees, a valve, the flow meter, both kinds of pump, the tube ends, the power inlet and the CO2 regulator — and the faucet lever above came from it. A scan now sets a part's shape, while calipers and prints that already fit set its fits. The valve came out a little longer than its drawing, which reopened five clearances inside the box.

## Films, and the site

Two films went up on 25 September. [Cold Soda on Tap — Inside a Home Soda Machine](https://youtu.be/aYyjj8i9WS8) is a narrated three-minute tour through the machine's own model, from the water supply through the cold core to the pour. [One Less Errand](https://youtu.be/WHO-V2DPTcs) is a 100-second animated short about the trip to the store a glass of soda should not need; it now plays on the home page, under the sign-up form.

The walkthrough page the tour was cut from is retired, and every section of this site — Parts, Charts, Drawings, Boards and Cost — is now in everyone's navigation. In [Parts](/3d) the faucet can be viewed in either style and either finish.

## What one costs

The parts for one machine now come to $1,374.74, up from $1,329.97 at the start of the window. The cold core's shell and caps moved to glass-filled PET, and the flavor pump pair cost more once the KPHM400 was gone; the new diaphragm pump and the jet cap cost less than what they replaced. Building one takes 10 h 15 m of hands-on work and 164.8 printer-hours, about 15 lb of filament.

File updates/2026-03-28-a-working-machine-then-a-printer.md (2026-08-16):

---
title: A working machine, then a printer
start: 2026-03-07
end: 2026-03-28
kind: period
image: /update-images/2026-03-28-prototype.png
image_alt: The prototype installed under the kitchen sink, pouring.
lede: The under-sink prototype gained its full software stack, then a production 3D printer turned the project toward a manufacturable appliance.
---

The repository opens on a machine that already pours. A carbonator, three peristaltic pumps, flow sensors, solenoid valves and three matte-black faucets were installed under the kitchen sink before the first commit, at about $1,814 in parts.

## The software stack

The controller went from one chip to three, built from one project: the main board that reads flow and drives the pumps, a round touchscreen with a rotary knob for configuration, and a small round display that shows the selected flavor. Settings and uploaded flavor artwork survive a power cycle in on-chip flash. A clock module keeps hourly pour statistics per flavor. A wash-cycle state machine exists in the firmware; its valve board is pinned but not installed.

{{fig:three-boards}}

An iPhone app arrived on 13 March and reached about 3,500 lines of Swift. It finds the machine over Bluetooth, edits flavor ratios, uploads and resizes artwork from the photo library, and shows pour statistics.

The link between the three boards was replaced with a standard framing protocol at three times the previous data rate. All three boards were flashed and tested together on 21 March, image uploads completed, and no link failures were observed.

## A build guide

The machine became something a stranger could rebuild: eight photographs of the installed hardware, a demo video of a pour, complete pin tables for all three boards, a plumbing document, and a costed parts list.

## 22 March

A Bambu Lab H2C printer with its multi-material system, six hotends and ten kilograms of filament — about $3,300 — plus a 72-inch workbench, digital calipers, a filament dryer and four dry boxes. The domain homesodamachine.com was registered the same day. Two commits landed on it.

The calipers arrived on the 24th and were used immediately. Three bought parts — a peristaltic pump, a solenoid valve, a push-fit union — were measured and photographed into thirty dimensioned images, replacing datasheet estimates.

## The first parts, and their deletion

A product vision followed: a 220 × 300 × 400 mm enclosure printed as two halves that snap together permanently, two collapsible syrup bags lying diagonally inside, and a pump cartridge the owner can swap, released by squeezing a hidden plate. Beside it, a requirements document keyed to the printer just bought — minimum wall thickness, overhang limits, hole-shrinkage allowances, layer orientation for snap arms.

Three mechanisms reached finished 3D geometry and were removed before the period closed. The outer enclosure, both halves, was finished after midnight on 28 March and deleted twenty minutes later. A bag cradle went the same morning. The pump cartridge ran through the design pipeline twice in one day, the second pass fanned out across ten sub-components, and was deleted five minutes after that pass finished.

What survives is two solid models: the lower cradle and upper cap of a permanent cage for a 2 L syrup bag. Nothing was printed in these four weeks.

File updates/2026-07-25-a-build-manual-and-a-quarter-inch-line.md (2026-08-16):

---
title: A build manual, and a quarter-inch line
start: 2026-07-19
end: 2026-07-25
kind: week
image: /update-images/2026-07-25-card.png
image_alt: One card from the 94-card printed build deck.
lede: The whole appliance got a printed bench manual, and the internal water line was rebuilt to one tube size.
---

A 94-card printed build manual came into existence — one card per hand operation, covering all twelve subsystems from welding the pressure vessel through burn-in and packing. It ships as 94 rendered pages and a print-ready PDF, with a renderer, a build script, a browser view of the deck, and a check that fails the build if a card's content overflows, spills into another band, or is silently clipped.

The stock to print it on arrived inside the week: 100 sheets of 4×6 gloss on 25 July, with letter-size following. An Epson EcoTank already on hand was entered on the tools ledger with its borderless page sizes and media settings, since it is the machine that produces the deck.

The internal water line was rebuilt to stay at ¼ inch from the backflow preventer to the pump. The flare adapter is now a two-fitting stack stepping straight to ¼ inch, the run is ¼-inch tubing, and the flavor tap is a ¼-inch union tee on the outlet. Three-eighths survives only as two short reinforced-PVC stubs clamped to the pump's own barbs, which are moulded into its head. A master water shutoff was added upstream of the pump, and the topology document now states that this valve is not part of the flavor manifold.

{{fig:water-path}}

Four purchased plumbing parts moved to the abandoned list with that change: the 3/8-inch flare-to-barb adapter, the tee that was the old flavor tap point, its branch adapter, and 10 ft of 3/8-inch silicone tubing. Two wire products went the same way — a 12-conductor jacketed cable that stiffens when cold, and a 100 ft spool of 24 AWG. Every low-voltage run now comes off one 22 AWG black spool inside braided sleeve.

The enclosure's interior was packed: pump, discharge chain, valve trays, drip pan, hopper, compressor shroud, condenser and cold-core mounts all placed relative to each other. Out of it came a coupon — the full four-piece enclosure reduced to 159 × 140 × 154 mm, keeping every seam, cross-pin ladder, display housing and rear port at full size. Two new printed parts were born beside it: a bridge holding the carbonator's reed sensors vertical, and a ring the cold core stands on.

Measuring the model became something the code does. Five new scripts let any generator ask the assembled solids where a part is, how close two parts come, and whether a candidate fits at a proposed position — with every query required to raise rather than return a quiet zero when it cannot measure.

On 24 July an order went to a water-systems supplier for the flare-to-¼-inch adapter, 10 ft of reinforced clear PVC and stainless hose clamps a size up — the parts the rebuilt water path needs.

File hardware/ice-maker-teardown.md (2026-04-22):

# Ice Maker Teardowns

Two countertop ice makers were purchased for harvesting refrigeration components (compressor, condenser + fan, capillary tube, filter-drier). See `hardware/future.md` for how the harvested parts fit into the cold core assembly.

## Two architectural paths for the cold core

As of 2026-04-18, the cold core design has two live options. Keep-vs-discard decisions below depend on which path wins.

- **Path A — custom SS carbonator + new evaporator coil.** Discard the factory finger-plate evaporator; wind a custom copper coil around a fabricated 304 SS racetrack carbonator. Refrigerant loop must be opened (cut into the suction and cap-tube sides of the factory evaporator), so factory charge must be vented, drier replaced, system evacuated, and recharged. This path is the one `future.md` describes.
- **Path B — factory evaporator kept in place, FDM-printed pressure vessel around it.** Keep the factory finger-plate evaporator wired in-circuit, exactly as shipped. Surround it with a PA6-CF structural shell lined with TPU (the TPU is the pressure boundary; the CF shell carries hoop stress). The refrigerant loop is never opened — factory charge stays sealed, no vent / recharge needed. The evaporator's cold fingers become the internal geometry of the vessel.

Under Path B the evaporator, the cap tube, the filter-drier, and the suction line all stay intact and move out of the "discard" column. The hot-gas bypass solenoid is still deleted (we want steady cold, not harvest cycles) under both paths.

R-600a is carved out of the EPA Section 608 venting prohibition as a natural refrigerant, so no 608 certification is legally required for either path. Standard (non-hydrocarbon-rated) HVAC vacuum pump and manifold are fine — we vent to atmosphere rather than recover, so recovery-equipment hydrocarbon compatibility is moot.

---

## Unit A — Generic countertop, 8 cubes / 6 min

- ASIN: **B0F42MT8JX**
- Price: $63.80
- Rated output: 26 lb/day
- First teardown: 2026-04-17

### Refrigerant

**R600a (isobutane).** Flammable. Charge is small (well under the 150 g UL 60335-2-89 limit for small appliances; factory label will list the exact mass). Brazing anywhere in the sealed loop requires the charge to be vented first — do not heat a pressurized R600a circuit.

### Refrigerant circuit topology (verified by disassembly)

```
    ┌── discharge ──► condenser ──► filter-drier ──► capillary tube ──┐
    │                                                     (bonded to   │
compressor                                                suction line)│
    │                                                                  ▼
    └── suction ◄──────────────────────────────── evaporator ◄─────────┘

    side branch:  compressor discharge ──► hot-gas bypass solenoid ──► evaporator
                  (active only during harvest cycle — delete for our use)

    not in the loop: compressor process tube (factory charge port, dead-end stub)
```

This matches standard R600a small-appliance practice. Verified by tracing the tubing on this unit during teardown, not assumed from reference material.

### Compressor

- Manufacturer: NingBo Anuodan Machinery Co., Ltd
- Model: **HD48Y11**
- Hermetic reciprocating, 1-phase, thermally protected, UL / CSM listed
- Larger than intuition suggests for a $64 appliance — this is normal. R600a hermetic cans have a floor size set by the motor, piston, and oil sump regardless of rated capacity. Freezing cubes in six minutes demands real wattage; this is likely in the 90–120 W cooling-capacity range, which is plenty for holding a carbonator at service temperature.

### Condenser

Finned-tube forced-convection condenser with its own fan shroud (fan not yet separated in photos). Standard wire-and-plate construction. Reuse as-is — orient for front-of-enclosure mounting per the enclosure layout in `future.md`.

### Filter-drier

A fat copper cylinder sits between the condenser outlet and the capillary tube inlet. It holds a molecular-sieve desiccant charge that traps residual moisture and debris — moisture in an R600a system freezes at the capillary tube orifice and causes intermittent loss of cooling, so the drier is load-bearing for reliability, not optional.

Label on this unit's drier:

- `8.05.08.044` (leading digit ambiguous — could be `0`)
- `60-130-05` — almost certainly the drier's model / part number. Useful if sourcing a drop-in replacement from the same supply chain; not confidently decodable without the manufacturer.
- `20251107 A-1` — manufacturing date code, 2025-11-07, line/shift A-1.
- Small stylized logo at left (manufacturer mark, not identified).

**Desiccant replacement rule:** once the refrigerant loop is opened (unbrazing for re-piping), the drier's desiccant has absorbed atmospheric moisture and is spent. Replace the drier before recharging. This is standard practice, not optional — reusing a saturated drier gives a short service life and eventual capillary icing.

### Capillary tube + suction-line heat exchanger

Downstream of the filter-drier, the metering device is a hair-bore **capillary tube** (not a TXV — cheaper, no moving parts, fine for fixed-load systems like ours). ID is roughly 0.03″ (well under 1 mm) — visibly thinner than you'd think anything could flow through, and that is the entire point. This single tube drops pressure from condenser side (~100 PSI) to evaporator side (~5–10 PSI for R600a) across its length. Mass flow for a 100 W-class system is a fraction of a gram per second, so the tiny bore passes the full charge just fine.

Physical path through this unit, start to finish:

1. **Exits the filter-drier** (cap tube is brazed into the drier's outlet end).
2. **Runs bonded alongside the suction line** for most of its length — this is the passive internal heat exchanger. Cold return gas from the evaporator subcools the liquid refrigerant before it flashes, increasing effective capacity at zero cost.
3. **Coils up in a short helix** right before the evaporator inlet — packaging, to fit the required length into a small area and manage any final pressure trim.
4. **Enters the evaporator.**

Keep the bonded cap-tube-plus-suction-line pair intact when re-piping — separating them hurts efficiency for zero benefit. The helical coil at the evaporator end is also worth preserving as-is; if total cap length changes (e.g., the evaporator is relocated when we swap the cold plate for our carbonator coil), a refrigeration tech recalculates cap length for the new load, rather than guessing.

### Process tube (the "dead-end" copper stub)

A short (~2″) copper tube closed with a pinched-and-brazed tip **sticks straight out of the compressor body** and connects to nothing else — it is genuinely a dead end. This is the factory charging port. The process is: evacuate the system through this tube, inject the refrigerant charge, then crimp and braze the tip shut. It has no flow during operation. This is where recovery and recharge will tap in during reassembly — either by cutting the crimped tip and brazing on a piercing saddle / access port, or by installing a bolt-on Schrader saddle over the tube.

Do not confuse with the capillary tube. Process tube = fat short stub on the compressor, pinched shut, goes nowhere. Capillary tube = long hair-thin line threading through the main loop between filter-drier and evaporator.

### Hot-gas bypass solenoid (DISCARD for our use)

A small AC solenoid valve is teed into the refrigerant circuit:

- Label: **SOLENOID VALVE — AC 110V 50/60Hz 4/4.5 W — TIANHAQ 25.10.17**
- Function in ice maker: during the harvest cycle, this valve opens and routes hot compressor discharge gas directly into the evaporator (bypassing the condenser and capillary tube), warming the cold fingers so formed cubes release and drop. Without it, an ice maker has no way to get cubes off the evaporator.
- Function in our build: **none.** We want continuous steady cold around the carbonator, not a harvest cycle. Remove the valve entirely when re-piping, or (if it's more convenient to leave physically in place) never energize it and verify the bypass path is sealed.

### Evaporator cold plate

A stainless-finger cold plate, purpose-built for ice-cube formation. Disposition depends on which cold-core path wins (see top of document):

- **Path A:** cut out during re-piping; replace with custom copper coil around the SS carbonator. The suction-side connection point moves to the new coil.
- **Path B:** keep in place, wired to the factory loop; build the printed pressure vessel around the finger geometry. The cold fingers become part of the vessel's internal topology.

### Powering and control (AC wiring)

The compressor is a single-phase AC hermetic with a **combined PTC start relay + overload protector** clipped to its terminal block. External connection is **two wires (black + white) coming out of that module**, not directly from the compressor pins. Believed to be **110–120 VAC** based on US market origin and the 110 V rating on the hot-gas bypass solenoid — verify the compressor nameplate before energizing.

For bench testing, plug into standard 120 VAC through an **inline fuse** (5 A fast-blow is comfortable for expected ~1 A running + LRA inrush). A Kill-A-Watt inline lets you observe the LRA spike, steady running draw, and confirm the compressor is doing real work rather than just humming.

Safety:
- **R600a is flammable.** Do not energize after physical damage, near open flame, or if a butane smell is present near the compressor. The factory loop is sealed from the factory, so there's no leak risk during teardown *inspection* — leak risk only appears if the loop is opened for Path A work.
- **Minimum off-time of 3 minutes** between power-off and power-on is a hard rule. The high-side pressure has to bleed through the capillary tube and equalize with the low side before restart, or the motor stalls against head pressure until the overload trips. Repeated hot-restart is a textbook way to burn out a hermetic compressor.

For ESP32 control:
- **Reserved GPIO: pin 14** on the main ESP32-DevKitC-32E. Not a strap pin, not input-only, not reserved for flash/PSRAM. See `hardware/wiring/future-esp32-pinout.mmd` for the full pin map.
- **Preferred: solid-state relay (SSR)** on the AC hot leg. 25 A SSRs (Fotek SSR-25 DA class or a quality-tier Crydom) take 3–32 VDC on the input and switch 120/240 VAC on the output. ESP32 GPIO drives the input directly. Mount to a heatsink — expect ~1 W dissipation per amp switched. Zero-crossing SSRs reduce EMI from inductive switching.
- Alternative: a mechanical motor-rated relay or contactor (e.g. Omron LY2) driven by a small NPN transistor + flyback diode from the ESP32. Works fine, audibly clicks, limited cycle life.
- **Firmware must enforce the 3-minute minimum-off-time** as a guard — the SSR will switch every loop iteration if told to, and that will destroy the compressor within days. Wrap the ON/OFF call behind a "can I switch right now?" check against the last-transition timestamp. A hysteresis band around the temperature setpoint (e.g., ±1 °C) is needed for the same reason — you want long cycles, not rapid thrash.

### Summary — keep vs discard for this unit

| Part | Disposition |
|---|---|
| Compressor | Keep |
| Condenser + fan | Keep |
| Capillary tube (bonded to suction line) | Keep — do not separate |
| Filter-drier | Keep in place; replace with fresh drier before recharge if the loop is opened |
| Process tube | Keep — vent/recharge access point |
| Hot-gas bypass solenoid | Discard / bypass |
| Evaporator finger plate | Path A: discard. Path B: keep in place as the vessel internal geometry |
| Thermostat / harvest-cycle controller | Discard (custom ESP32-S3 firmware replaces it) |

### Open items

- Factory refrigerant charge mass (read from the nameplate once fully exposed)
- Compressor rated cooling capacity in W — confirm against expected load of holding ~1.5 L of carbonated water at 2 °C against cabinet-ambient
- Physical dimensions of compressor + condenser pair, for enclosure layout
- Decide whether to save photos to `hardware/ice-maker-teardowns/unit-a-b0f42mt8jx/raw-images/` alongside this doc

---

## Unit B — Frigidaire EFIC117-SS

- ASIN: **B07PCZKG94**
- Price: $78.70
- Rated output: 26 lb/day
- Teardown: pending

To be filled in after teardown.

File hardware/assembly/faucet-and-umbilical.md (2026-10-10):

# Faucet and Umbilical

[Illustrated faucet assembly guide](../faucet-assembly-guide/README.md):
18 Letter bench pages, with the [rear display wiring on page 2](https://homesodamachine.com/read/faucet-assembly-guide/faucet-assembly-guide.pdf#page=2).

The production procedure for the above-counter fixture stack and the 4-tube umbilical that connects it to the +Y wall of back-top — the visible half of the appliance from the user's perspective. The faucet and the umbilical ship as **one permanently-attached unit**: the retained donor washer and nut are factory-preloaded on the bare shank before the carbonated-water LLDPE tube is clamped into the Westbrass's upstream compression port, and that tube is never separated again. The two flavor LLDPE tubes route through the faucet-shell's pill slot up into the printed gooseneck's dispense channel where they terminate at the printed tip — black end to end on a Black faucet; on a White faucet white through the faucet, each joined to its black run in the umbilical by a John Guest union inside the braid's top. The customer (or their installer) drills the 1-3/8" countertop hole, drops the complete faucet+umbilical through it from above and pushes it back until the rear tube bundle reaches the hole's wall — the faucet seats itself, nothing is measured, and the gasket still covers the hole behind by [5.132 mm](GASKET_COVER) there — **slides the under-counter plate laterally into the captive mount stack from below** so the shank and tubes enter through the plate's open-edge channels and seat in their terminal pockets, then hand-tightens the same retained nut. At the far end, the three beverage tube tails push into the PP1208E bulkheads and the 4 mm OVER tail enters its ABU44M-E bulkhead on the appliance's +Y wall of back-top and the signal ribbon's plug clicks into the keystone jack beside them.

This bench runs in parallel with the main appliance chain. Its inputs are upstream of [`pressure-vessel.md`](/hardware/assembly/pressure-vessel.md) and its output ships in the carton alongside the finished enclosure produced by [`finish-pack-ship.md`](/hardware/assembly/finish-pack-ship.md). Design intent for the user-facing surface lives in [`/hardware/README.md`](/hardware/README.md) "User-facing surfaces"; the gooseneck carries one 3/8" soda faucet tube and two 1/4" flavor tubes out over the glass — see [`/hardware/printed-parts/faucet/faucet-shell/`](/hardware/printed-parts/faucet/faucet-shell/) and that part's [`MATERIAL.md`](/hardware/printed-parts/faucet/faucet-shell/MATERIAL.md).

The drain ends square with local mouth clearance in the tip. Its round Ø4 mm
underside hole is a visible fault-drip indicator over the bowl. Continuous close-fitting
passages carry the tubes and conductors; incidental leakage into
the housing is accepted during this major fault. Aim the faucet into the bowl
and keep the hole exposed after tightening the mounting nut.

## Scope

In: the separate PET-GF15 faucet shell pieces, display cover and above-counter plate; the printed lever; a bare harvested Westbrass with its washer and shank nut; the display and assembly fasteners; the printed TPU thimble and above-counter gasket. These are assembled around the tubes and ribbon at this bench following [`faucet shell assembly`](/hardware/printed-parts/faucet/faucet-shell/ASSEMBLY.md). Also required: one SendCutSend 0.060" SS under-counter plate (ships loose in the install bag — slides onto the umbilical at install through its open-edge channels); 3× 1/4" OD LLDPE umbilical tubes cut to length (1× blue carbonated-water + 2× black flavor), and on a White faucet 2× white 1/4" OD LLDPE flavor runs for the faucet and 2× John Guest PP0408W unions joining them to the black; one 3/8" OD LLDPE soda faucet tube for the gooseneck, in the faucet's finish; one white 4 mm OD LLDPE OVER tube; one Siptenk 1/4" OD brass tube stiffener for the carbonated-water tube end that lands in the Westbrass's upstream compression port; CARGEN nitrile foam pipe-insulation segments; PET braid sleeve segments; one PET-GF umbilical organizer; four printed tube collars; one unterminated BNTECHGO 28 AWG 4-conductor signal cable carrying the faucet display link (SIG-6: TX / RX / 5 V / GND) through the countertop, plus one loose RJ11 6P4C modular plug for its wall end.

Out: a complete above-counter fixture stack permanently attached to its umbilical — Westbrass captured in the faucet shell; retained donor washer and nut captive on the shank; blue carbonated-water supply connected at the Westbrass's lower upstream compression port; 3/8" soda faucet tube sealed into the top port and routed through the gooseneck; two flavor LLDPE tubes routed through the shell's pill slot and gooseneck to the printed tip, on a White faucet white to their unions inside the braid's top and black from there; four sleeved umbilical tubes terminated bare and push-to-connect-ready at the +Y wall of back-top, each wearing its own printed collar on the bare stretch below the braid; foam insulation only on the cold blue tube; factory-fitted SIG-6 ribbon + tube bundle co-sleeved below the countertop, with one organizer below the mounting workspace. Bagged with the one loose part the countertop mount needs, the SS under-counter plate (the TPU gasket and donor mount hardware are already captive on the faucet), drop-shipped inside the appliance carton.

Not in scope: countertop drilling itself; the customer-side install steps — drop-through from above, slide the under-counter plate laterally above the captive washer, hand-tighten the same retained nut, push-into-PP1208E at the +Y wall of back-top — covered in the install guide that ships with the appliance ([`/hardware/install-guide/`](/hardware/install-guide/README.md); packing and content contract: [`/marketing/unboxing-and-installation.md`](/marketing/unboxing-and-installation.md)). The J3 loom that lands SIG-6 on the main board inside the cabinet is `wiring.md`; no signal conductor is cut, crimped or stripped in the field — the customer's whole share of SIG-6 is pushing one plug into one jack.

## Inputs per appliance

Per-unit BOM lives in [`/hardware/ledger/bom.md`](/hardware/ledger/bom.md) §9 (Dispensing — Westbrass, under-counter plate, foam insulation) and §8 (Flavor subsystem — Siptenk stiffener for the carbonated-water tube end at the Westbrass upstream port). The table below is the procedure-level summary; bom.md is the source of truth for per-unit allocation and cost.

The blue 1/4" carbonated-water supply compression-connects to the bottom of the Westbrass with a Siptenk stiffener under the brass ferrule. Water rises through the Westbrass and leaves its top port in a separate 3/8" LLDPE soda faucet tube. That soda faucet tube and the two 1/4" flavor tubes share the printed gooseneck and exit at the tip; only the flavor pair enters through the shell's pill slot.

| Item | Source | Notes |
|---|---|---|
| PET-GF umbilical organizer × 1 | [`umbilical-organizer`](../printed-parts/faucet/umbilical-organizer/README.md), BOM §7 | Ø32 × 10 mm; three Ø[6.65 mm](ORGANIZER_TUBE_BORE) beverage bores from the accepted A fit, a Ø[4.40 mm](ORGANIZER_DRAIN_BORE) drain bore from B and a loose flat [5.4 × 1.8 mm](ORGANIZER_CABLE_SLOT) signal slot. Its rear row follows the mounting plate. Thread it before the flavor unions, blue-tube compression connection and signal plug. |
| Separate faucet shell pieces, display cover, above-counter plate, display and bare Westbrass | Parts and hardware listed in [`faucet shell assembly`](/hardware/printed-parts/faucet/faucet-shell/ASSEMBLY.md) | PET-GF15 prints, M3 heat-set inserts and screws, harvested donor body and retained lever. Keep the donor washer and shank nut separate until the gasket is fitted. Assemble around the soda tube, flavor pair and unterminated ribbon during step 2. |
| Siptenk 1/4" OD brass tube stiffener × 1 | B0FM77LLM1 (100-pk) | Inside the carbonated-water LLDPE tube end that lands in the Westbrass's upstream compression port, so the soft tube doesn't crush under the brass ferrule. Only one stiffener per build — the two flavor tubes do not enter any compression port and need no stiffener. |
| TPU above-counter gasket (printed) | [`/hardware/printed-parts/faucet/above-counter-gasket/`](/hardware/printed-parts/faucet/above-counter-gasket/) | Sits between the above-counter plate's underside and the countertop top surface. **Installed at this bench**, threaded over the flavor tails, unterminated ribbon and shank during step 2 before the retained mount hardware and blue-tube connection go on. Stays permanently on the shank from this point forward. Customer never touches it. |
| TPU O-ring (printed) | [`/hardware/printed-parts/faucet/tpu-o-ring/`](/hardware/printed-parts/faucet/tpu-o-ring/) | TPU 90A **thimble** (closed bottom with a Ø [6.5 mm](CAP_HOLE_D) centered hole, open top) that seats in the harvested Westbrass's Ø [10 mm](WESTBRASS_PORT_D) top water port. Outer Ø [10.44 mm](ORING_OUTER_D) ([0.22 mm](WESTBRASS_SQUEEZE) radial squeeze against the port wall), cylinder ID Ø [9.2 mm](ORING_INNER_D) ([0.1625 mm](LLDPE_INTERFERENCE) interference grip on the 3/8" LLDPE OD), [15.6 mm](TOTAL_H) total height ([2.1 mm](ORING_CAP_T) cap + [13.5 mm](CYL_L) cylindrical sealing band). Two seals in series: radial compression along the cylinder + face seal where the LLDPE's bottom end presses against the cap; cap hole sized between LLDPE ID ([6.35 mm](LLDPE_ID)) and OD ([9.525 mm](LLDPE_OD)) so the tube bottoms out positively and water flows through the cap hole into the LLDPE bore. Install order: thimble cap-down into the port first, then push the 3/8" LLDPE down through the open top until it bottoms on the cap. Consumable — expect to use a fresh thimble on any future re-assembly. |
| 3/8" OD LLDPE (soda faucet tube), in the faucet's finish | Black: FWS 25 ft stock, purchase `WEBFWS100673540` ([`purchases.md`](/hardware/ledger/purchases.md)). White: neoFlo LLDPE6-WHITE ([`bom.md`](/hardware/ledger/bom.md) §9) | Cut to [330](SODA_FAUCET_CUT) mm. Internal to the faucet: sealed into the Westbrass's top water port by the TPU thimble, then routed through the center gooseneck channel to the printed tip. It is not an umbilical tail. |
| SendCutSend 0.060" 316 SS under-counter plate | `under-counter-plate.dxf` ([`/hardware/cut-parts/faucet/under-counter-plate/`](/hardware/cut-parts/faucet/under-counter-plate/)) | Purchased S4177511 profile: single-piece Ø [54.45 mm](PLATE_D) disc, Ø [12.6 mm](SHANK_HOLE_D) shank pocket and [13.4 mm](PILL_L) × [7.05 mm](PILL_W) rear pocket. The [12.6 mm](SHANK_HOLE_D) shank channel and [7.05 mm](PILL_W) rear channel open in DXF −Y (world +X), with R [1.5 mm](FILLET_R) channel-mouth fillets. F1/D/F2 and the flat ribbon share the rear channel toward its open side. The printed mounting stack and routing fit this fixed steel profile. Order qty 1 per appliance. |
| 1/4" OD LLDPE, blue (carbonated water) | FWS neoFlo blue spool ([`/hardware/ledger/bom.md`](/hardware/ledger/bom.md) §3) — one of the four the machine is plumbed in, per [`/hardware/printed-parts/enclosure/y-wall-of-back-top/README.md`](/hardware/printed-parts/enclosure/y-wall-of-back-top/README.md) "Umbilical port — tube identification" | Cut to length once; color-coded blue to match the blue-ringed PP1208E bulkhead on the +Y wall of back-top, and the same blue as the riser inboard of it |
| 1/4" OD LLDPE, black (flavor lines) × 2 | FWS bulk spool ([`/hardware/ledger/bom.md`](/hardware/ledger/bom.md) §3) | Cut to length once each: the whole flavor tube on a Black faucet, the umbilical's run from its union on a White one. Bare black at the wall, matches the two unmarked PP1208E bulkheads on the +Y wall of back-top |
| 1/4" OD LLDPE, white (White faucet flavor runs) × 2 | neoFlo LLDPE4-WHITE, the §3 tap-water spool ([`/hardware/ledger/bom.md`](/hardware/ledger/bom.md) §9) | White faucet only. Printed tip to its union, through the faucet |
| John Guest PP0408W 1/4" union × 2 | FWS PP0408W ([`/hardware/ledger/bom.md`](/hardware/ledger/bom.md) §9) | White faucet only. Joins each white flavor run to its black run, end to end inside the braid's top — [`/hardware/reference/jg-pp0408w/`](/hardware/reference/jg-pp0408w/) |
| CARGEN nitrile foam pipe insulation, 1/4" ID × 3/8" wall, 1-ft segments | B0D2XFK337 ([`/hardware/ledger/bom.md`](/hardware/ledger/bom.md) §9) | **Cold tube only.** Foam ships as 1-ft segments and is installed segment-at-a-time. Five segments per umbilical, covering [1261](FOAM_LENGTH) mm of the blue tube |
| Cable sleeve — Alex Tech 1" PET expandable braid, five 1-ft segments | B075VRDS53 ([`bom.md`](/hardware/ledger/bom.md) §11 "Umbilical sleeve") | Over all four tubes + the signal cable, one segment to each foam segment, on the foam's own run. 1" nominal expanding 50%; the pack opens it to Ø[32.84 mm](SLEEVE_BORE). ~5 ft per build |
| Printed tube collar × 4 | [`/hardware/printed-parts/faucet/tube-collar/`](/hardware/printed-parts/faucet/tube-collar/README.md) | `tube-collar-carb` on the blue tail, `tube-collar-flavor-a` and `-flavor-b` on the two black. The +Y wall of back-top's own chip bored for the tube and run [30 mm](COLLAR_LENGTH) along it — same word, same spool, threaded on end-first up to the braid's own end. `tube-collar-drain` identifies the white 4 mm drain. The other two stations' collars go onto the customer's tap-water run and CO2 tether at [`finish-pack-ship.md`](/hardware/assembly/finish-pack-ship.md) §6 |
| Umbilical signal cable (BNTECHGO 28 AWG 4-conductor ribbon) | B07PNPHWMG ([`/hardware/ledger/bom.md`](/hardware/ledger/bom.md) §9) | Single run from the gooseneck faucet display down to the wall, carrying SIG-6 (faucet display: TX / RX / 5 V / GND). [Measured received section](../reference/bntechgo-signal-ribbon/physical-observations.json): [1.18 × 4.6 mm](RIBBON_SECTION). |
| RJ11 6P4C modular plug, 3-prong × 1 | B0DK4V733Q ([`/hardware/ledger/bom.md`](/hardware/ledger/bom.md) §11) | Crimped onto the ribbon's wall end at step 2. Mates the RiteAV keystone jack on the +Y wall of back-top ([`../printed-parts/enclosure/y-wall-of-back-top/README.md`](/hardware/printed-parts/enclosure/y-wall-of-back-top/README.md) station 7). 3-prong contacts for stranded. |
| 2× low-capacitance ESD TVS (ESD9B3.3-class / PESD3V3-class, SOD-923) — **optional** | onsemi ESD9B3.3ST5G or Nexperia PESD3V3L1BA (≤ 15 pF, 3.3 V, bidirectional) | **Optional** faucet-end ESD clamp (defense-in-depth only). The primary faucet-UART clamp is now on the main board (D10/D11 at U1), so a cable-end TVS is **not required** — fit only if a builder wants a second clamp at the user-touch source (see the ESD note below). |

Tooling (per-build-amortized only; single-asset tools live in [`/hardware/ledger/purchases.md`](/hardware/ledger/purchases.md), not here): Mudder PEX/PE tube cutter (the cold kit's own, [`/hardware/ledger/bom.md`](/hardware/ledger/bom.md) §14 — one SKU at the bench and in the kit).

### Faucet-display ESD protection (on the main board — no build step here)

The faucet display is the one user-touched surface on the appliance, at the far end of a ~1 m
umbilical — so its two TTL UART lines are the most ESD-exposed nets on the main board. The **primary**
clamp is now **on the main board, at the ESP32**: each TTL line is clamped by a low-cap TVS shunting
the U1-side of its series resistor to the GND plane — **D10 on IO33 (TX), D11 on IO35 (RX)**, onsemi
**ESD9B3.3ST5G** (SOD-923, 3.3 V, bidirectional, ~15 pF), each with a via-in-pad straight to the
plane (shortest loop). A strike up the ribbon is current-limited by the 220 Ω series resistor (R26/
R27) and clamped to ~3.3 V at the ESP32 pin. **This means no ESD build step is required at the faucet
end.**

- **Optional (defense-in-depth only):** a builder may still fit **2× low-cap ESD TVS** at the
  faucet-display connector — one from each TTL line to the faucet-side GND — for a second clamp at the
  user-touch source. Same part class (**ESD9B3.3 / PESD3V3, ≤ 15 pF, SOD-923**, e.g. onsemi
  ESD9B3.3ST5G or Nexperia PESD3V3L1BA), mounted on the last ~10 mm of ribbon (the connector's
  carrier/adapter PCB or a small flex/dead-bug tab, since the stock **Waveshare
  ESP32-S3-Touch-LCD-1.47** module carries no spare pad), GND stub **< 5 mm**. This is not required —
  the main board already clamps the ESP32 pin.
- The 5 V and GND conductors are not clamped (rail + return); only the two TTL signals.

Full spec and part rationale: [`/hardware/assembly/cable-assemblies.md`](/hardware/assembly/cable-assemblies.md)
"Faucet-display ESD protection (SIG-6)", with the main board placement in
[`/hardware/pcb/pcba/jlcpcb-parts.md`](/hardware/pcb/pcba/jlcpcb-parts.md) (D10/D11) and
[`/hardware/pcb/pcba/pcba.tsx`](/hardware/pcb/pcba/pcba.tsx) (FAUCET block).

## Procedure

### 1. Cut the LLDPE tubes to length

Cut **1× blue carbonated-water at [1540](BLUE_CUT) mm**, the flavor pair in the faucet's finish, and **1× 3/8" soda faucet tube at [330](SODA_FAUCET_CUT) mm** from the finish's own 3/8" stock. Use the Mudder cutter for square ends without burrs.

- **Black faucet: 2× black flavor at [1963](FLAVOR_CUT) mm.**
- **White faucet: white flavor-a at [557](WHITE_A_CUT) mm and flavor-b at [515](WHITE_B_CUT) mm, black flavor-a at [1397](BLACK_A_CUT) mm and flavor-b at [1439](BLACK_B_CUT) mm.** Each white run reaches from the printed tip to its union's tube stop and each black run from the other stop to the tail, with [9.8 mm](UNION_GAP) of union between the two ends, so the tails land where a Black faucet's do. Flavor-b's union stands one union length above flavor-a's (step 2), so its white run is the shorter and its black run the longer.

The flavor pair follows [370.4](FAUCET_FLAVOR_RUN) mm of centreline above the shell foot, then passes through the plate, gasket and countertop and down past the unions' stations into the pack. The blue tube starts at the donor shank's lower compression port. The factory cut difference of [423](CUT_DIFFERENCE) mm comes from those complete CAD routes, including both lower return steps, the gathers and the splayed tails. The resulting tails land within [0.17](TAIL_OFFSET) mm of one plane before trimming the outlets flush. These lengths preserve the blue tube's installed reach.

The design length sums a measured half and an assumed half:

| Term | mm | Basis |
|---|---:|---|
| Drop, countertop underside → appliance top plane | 418 | 34.5" carcass − 4" toe kick − 3/4" deck = 755.7 mm interior clear, less the enclosure height |
| Down the rear face to the flavor-bulkhead axis | 42 | CAD |
| Turn-in at the wall — lead + 90° at R12 + collet | [60](TURN_IN) | CAD |
| Horizontal inside the cabinet, faucet hole → drop line | 380 | 36" sink base: faucet on the sink centreline, appliance at one end |
| Service loop — the appliance comes forward to reach its own +Y wall of back-top | 300 | pull-forward to put the +Y wall of back-top at the cabinet face |
| **Below-counter subtotal** | **1200** | |
| Countertop slab | 30 | 3 cm stone; routing allowance extends to 38 mm, with donor clamp engagement assessed separately |
| TPU gasket + above-counter plate | [6](PLATE_GASKET) | CAD |
| Gooseneck centreline, shell foot → printed tip | [370.4](FAUCET_FLAVOR_RUN) | CAD |
| **Flavor tube, nominal installed** | **[1606](FLAVOR_NOMINAL)** | |
| **Blue tube, nominal installed** | **[1186](BLUE_NOMINAL)** | CAD: compression port below the countertop underside |

**Reach beyond nominal: 350 mm per tube**, held separately from the sum — 8 mm of countertop routing allowance, 25 mm for cabinet-height variance, 300 mm for an appliance at the far end of the sink base rather than the near end, 20 mm for two square cuts should the run ever be trimmed. The rounded factory cuts include this allowance and the small gather-path correction. The routing allowance does not establish the donor clamp's maximum countertop thickness; [faucet shell assembly](/hardware/printed-parts/faucet/faucet-shell/ASSEMBLY.md) records its thread budget.

The umbilical installs at this length, uncut: a nominal kitchen loops the reach in the cabinet, and that loop is the service loop that brings the +Y wall of back-top to the cabinet face ([`/marketing/install-envelope.md`](/marketing/install-envelope.md)). A second cut, taking the wall end down to the cabinet's own length, belongs to the cold kit's guide and not to the install — so do not cut tight here.

Cut one continuous white neoFlo LLDPE4M-WHITE 4 mm drain run to [1871](DRAIN_CUT) mm, including the supplied cabinet and service reach. Feed it between the flavors through the rear plate/gasket passage and shell, with the ribbon flat behind the bundle. The lower bundle sits toward the steel channel's open side and eases back to the centered neck arrangement inside the base. Below the counter use R25 bends around the two flavor unions and gather it against the opposite side of the cold-line foam under the common braid. With the tip separate, set the square drain end at its terminal datum, leaving the 3 mm mouth clearance empty; keep its bore clear of other tubes. Keep the supplied run long enough for the cabinet service reach and R25 bends. [ASSE drain assembly](/hardware/assembly/asse-drain.md) gives the fitting and routing sequence.

### 2. Assemble the faucet; preload the mount hardware

Start with the separate prints, bare donor, tubes and unterminated SIG-6 ribbon. Complete the base, neck and display steps in [`faucet shell assembly`](/hardware/printed-parts/faucet/faucet-shell/ASSEMBLY.md): seat the donor with the soda tube absent, lower the lever aft of its working position and slide it forward around the valve cylinder, then install the fresh TPU thimble and soda tube. The installed soda tube blocks the lever's aft disengagement. Feed the continuous drink tubes and flat insulated ribbon through the tip's smooth shared passage. Set the square-cut D end at its terminal datum with the 3 mm mouth clearance empty and the tube bore clear. Close the curved joint and plate, then connect and enclose the display. Set only the three beverage outlets flush with their symmetric face and verify lever travel and flavor flow. Leave the donor washer and nut off and the ribbon's wall end unterminated until the gasket is fitted. Drinking flow stays inside the LLDPE tubes and donor valve; fault discharge enters the common passage clearance and its Ø4 mm bottom hole.

- **Above-counter gasket.** Thread both flavor tails, the 4 mm drain tail and the ribbon's unterminated wall end through the gasket's matching passage, then pass the still-bare shank through its centre hole. Slide the gasket up until it sits flat against the above-counter plate. It stays there permanently.
- **Umbilical organizer.** Thread the unjoined flavor tails and drain through their corresponding bores, the unterminated signal ribbon flat through the loose [5.4 × 1.8 mm](ORGANIZER_CABLE_SLOT) slot, and the bare blue tube through the soda bore. Point the soda bore toward the shank, with the rear F1–D–F2 row and ribbon behind it matching the mounting plate. Hold the puck and adjust each tube with the other hand. Its upper face is [50.48 mm](ORGANIZER_PLATE_GAP) below the nominal steel plate at faucet Z=[-88 mm](ORGANIZER_TOP_Z), with [10 mm](ORGANIZER_LENGTH) of thickness. Keep it below the washer/nut working area, with straight parallel tube sections through it. The puck floats with the bundle and stays inside the top braid. The [selected round-bore profiles](../printed-parts/faucet/umbilical-organizer/physical-acceptance.json) use A's beverage fit and B's drain fit; the organizer layout and flat slot are unprinted.
- **Flavor unions (White faucet).** Push each white flavor tail into the top port of a PP0408W union until it bottoms on the tube stop, [16 mm](UNION_INSERTION) in, then push that flavor's black run into the bottom port the same way. The cuts hang flavor-b's union [91 mm](UNION_B_BELOW_PLATE) below the nominal under-counter plate once installed, with flavor-a's union end to end below it. Reserve straight F1/D/F2 and ribbon through the steel below a [38 mm](COUNTERTOP_MAX_THICKNESS) routing-envelope slab. Keep the upper bare lines close to that mounting row through the organizer. Begin the flavor R30 and drain R25 returns toward the unions 3 mm below the puck, leaving 7 mm between the completed flavor returns and the upper union. Keep these factory positions so the lower return bends clear the hardware throughout the routing envelope. A Black faucet's flavor tubes are one length each and nothing is joined.
- **Retained countertop hardware first.** Slide the donor washer onto the bare threaded shank, then thread the donor nut on loosely. Leave the clear gap above them that receives the countertop and the open under-counter plate at field install. From this point forward the washer and nut remain captive; they are never loose customer parts.
- **Carbonated water (blue tube).** Insert a Siptenk 1/4" brass stiffener fully into the blue LLDPE tube end that will land in the Westbrass. Push that stiffened end into the Westbrass's upstream compression port (the supply side that takes carbonated water *in*). The Westbrass's factory ferrule + nut clamp the LLDPE around the stiffener; hand-snug + 1/4 turn with a wrench.
- **SIG-6 plug.** With the plug's gold contacts facing you, nose up, cable down and latch behind, insert the four black ribbon wires **C1-C4 left to right into positions 2-5**; positions 1 and 6 are empty. C1 is the edge you mark white at both free ends before separating the ribbon. C1/VBUS goes to pin 2, C2/GND to pin 3, C3/TXD to pin 4 and C4/RXD to pin 5. The [connector picture below](#display-wiring-sig-6) shows the plug and exact jack terminations. The plug's own strain-relief bar closes on the ribbon's jacket, so the four IDC blades carry no tension. The ribbon is [1.18 mm](RIBBON_T) thick where the plug's slot is cut for flat cord nearer 1.9 — shim the last 15 mm with a wrap of tape or heat-shrink so the bar bottoms on something. Take a **3-prong** 6P4C plug: the ribbon is 16 strands of 0.08 mm and the two-tine contact is the solid-conductor geometry.

#### Display wiring (SIG-6)

In the installed faucet, **USB-C points toward the dispense face**; the opposite
end points up the gooseneck. The side-section inset below shows this orientation.

The display is the **Waveshare ESP32-S3-Touch-LCD-1.47**. Look directly at its
rear PCB, glass facing away, with **USB-C at the top**. The top four pads down
the **left** are VBUS, GND, TXD and RXD. P1's odd pin numbers run down that side.

Rear display orientation and the four SIG-6 connections

All four ribbon wires are **black**. Add a white index mark to one edge at both
free ends **before separating the conductors**. That is C1; count C1-C4 across
the ribbon from it. Preserve these identities while feeding the printed guide passages.

| Ribbon wire | Display pad / P1 pin | RJ11 plug and jack pin | Jack's printed USOC label | Main board J3 pin / net |
| --- | --- | ---: | --- | --- |
| C1, marked edge | VBUS / P1-1, +5 V | 2 | White/orange | 3 / V5 |
| C2 | GND / P1-3, 0 V | 3 | Blue | 4 / GND |
| C3 | TXD / P1-5, GPIO43 display TX | 4 | White/blue | 2 / IO35, main RX |
| C4 | RXD / P1-7, GPIO44 display RX | 5 | Orange | 1 / IO33, main TX |

RJ11 plug gold-contact view and RiteAV USOC punchdown slots, with exact black-wire and J3 assignments

At the **RiteAV CAT3 USOC jack**, punch down the black 22 AWG inboard leads:
**J3 3/V5 → jack 2 (white/orange), J3 4/GND → jack 3 (blue), J3 2/IO35 →
jack 4 (white/blue), J3 1/IO33 → jack 5 (orange)**. Those colors identify the
jack's printed terminal labels. Leave 1 and 6 open. Keep insulation on the
leads for the 110 IDC termination; trim outward and refit the dust cover.
With the main PCB's component side up and J3 at its lower edge, the silk reads
**GND, V5, IO35, IO33** from left to right, physical pins **4, 3, 2, 1**.

TX/RX use **3.3 V TTL, 921600 baud, 8N1**. Leave all other display pads open.
With J3 and USB disconnected, solder the four leads directly at these PCB
pads **after the conductors are routed through the tip**. The conductors remain continuously
insulated through the neck; stripping and soldering happen only at their dry
PCB ends. Leave enough free lead for the display/cover slide and lowering motion,
and keep it clear of the metal feet, components, retaining lips and USB socket.

With the main-board end unplugged, check continuity against the four specified
connections above, and check for adjacent-conductor and power-to-ground shorts.
After the unpowered check, power through J3 and
confirm boot, main-board flavor synchronization and bright-screen touch response.
The [guide's page 3](https://homesodamachine.com/read/faucet-assembly-guide/faucet-assembly-guide.pdf#page=3)
shows the joint/check; page 12 shows display fitting.

Pad order and P1 numbers come from [Waveshare's rear layout](https://docs.waveshare.com/ESP32-S3-Touch-LCD-1.47)
and [schematic](https://files.waveshare.com/wiki/ESP32-S3-Touch-LCD-1.47/ESP32-S3-Touch-LCD-1.47-Schematic.pdf).
GPIO direction and baud match [`base_link.cpp`](../../firmware/src_faucet/base_link.cpp)
and [`pins.h`](../../firmware/src_appliance/pins.h).
Physical J3 numbers include the wafer rotation in [`parts.tsx`](../pcb/pcba/parts.tsx).
Jack labels follow the [RiteAV CAT3 USOC body legend](https://www.riteav.com/products/riteav-rj11-phone-black-punchdown-type-keystone-jack-10-pack)
and [six-contact USOC terminal colors](https://leviton.com/content/dam/leviton/network-solutions/product_documents/instruction_sheet/Leviton-IST-41106-41108-Voice-Grade-Jacks.pdf).

At the wall end of all four tubes: **leave them bare and square-cut.** The installer pushes the white 4 mm OVER into its ABU44M-E socket and the three beverage tubes into their matching PP1208E sockets at field install; PP1208E's internal grab-ring + EPDM O-ring make the seal around the tube OD (same seal mechanism already in use on the reservoir-cap bulkhead per [`/hardware/printed-parts/cold-core/reservoir/reservoir.py`](/hardware/printed-parts/cold-core/reservoir/reservoir.py)).

### 3. Insulate and sleeve the run, a segment at a time

Per [`/hardware/printed-parts/enclosure/y-wall-of-back-top/README.md`](/hardware/printed-parts/enclosure/y-wall-of-back-top/README.md) "Umbilical bundle construction": **foam goes on the blue tube only.** The carbonated-water tube is the temperature-critical run.

First lay the umbilical signal cable alongside the four tubes, so it is inside every braid segment that follows. It is the BNTECHGO 28 AWG 4-conductor ribbon and carries the SIG-6 faucet-display link (TX / RX / 5 V / GND) through the countertop, per [`/hardware/wiring/ac-wiring-schedule.md`](/hardware/wiring/ac-wiring-schedule.md). It rides in the lane the braid leaves between itself and the tubes.

Then work up the run from the bare wall end, **one foam segment and one braid segment at a time**:

1. Slide a CARGEN foam segment up the blue tube to butt the one above it. The segments are a snug interference fit over 1/4" OD LLDPE; lubricate with a wipe of water if friction is high (no solvents — nitrile is solvent-sensitive). No gap at the butt.
2. Gather the two flavor tubes against the insulated blue tube and put D against the opposite side of the foam. Keep the signal cable inside the same braid, then slide the segment up to butt the braid above it.

The top braid segment covers the organizer and both White-faucet unions as well as its foam segment. Expand it over those parts before seating it. Subsequent segments cross bare tube and their own foam. A segment cut to cover one foam segment when it is opened over the bundle is longer than the foam segment: braid shortens as it expands, and how much is a bench measurement on the first build.

**Five of each** for the standard build, the foam covering [1261](FOAM_LENGTH) mm of the blue tube's [1540](BLUE_CUT) mm — bare [204 mm](FOAM_BARE_TOP) at the compression end, down past the unions' stations, and the last [75 mm](COLLAR_SLEEVE_TAIL) at the wall, where the installer separates the four tails for their identified push-connect ports. **The top braid segment runs on up past its foam**, [166 mm](SLEEVE_ABOVE_FOAM) further, over both unions on a White faucet and over the same stretch of the flavor tubes on a Black one, to the organizer’s upper face. A cold-kit trim takes whole segments off with it, foam and braid together, which is what the 1-ft granularity buys.

The braid opens to Ø[32.84 mm](SLEEVE_BORE) over the insulated pack, [103.2 mm](SLEEVE_GIRTH) of girth, and to Ø[31.07 mm](UNION_SLEEVE_BORE) over the unions, and lies on the tubes rather than standing off them in a circle. Over the Ø32 mm organizer, the modeled braid envelope is Ø34 mm. That leaves 0.465 mm nominal radial clearance in the Ø[34.93 mm](COUNTERTOP_HOLE_D) countertop hole; braid weave and folds are not represented in that clearance. The complete sleeved bundle is fed through the hole from above during installation; the foam-covered blue run sits below the counter when seated. The foam starts below the lower union, since a union beside it would be [40.5 mm](UNION_BESIDE_FOAM) across; at each union the bundle is one Ø[15.1](UNION_RING_D) union beside two 1/4" tubes.

What the blue (foamed) tube carries is identification, not orientation — it goes into the blue-ringed union, which is the east end of the row.

### 4. Thread a collar onto each tail

Slide one printed collar down each tube from its bare +Y wall end: `carb` on the blue, `flavor-a` and `flavor-b` on the two black, and `drain` on the white 4 mm tube. The beverage collars have 6.68 mm CAD bores on Ø[6.35](COLLAR_TUBE_OD) LLDPE; the drain collar has a 4.25 mm CAD bore. The [collar calibration](../printed-parts/faucet/tube-collar/README.md#the-bore) is scoped to its measured PETG article. Confirm that each finished PET-GF collar threads by hand down the whole [30 mm](COLLAR_LENGTH), without scoring the stretch of tube that must seal in its fitting.

Run each collar up the tube until it butts the braid's own end — [75 mm](COLLAR_SLEEVE_TAIL) short of the tail — and turn its flag outward, away from the bundle's axis, so no two face each other. All four come out level. Each stays where it is put on the bend the tube came off the spool with: the tube is never straight through [30 mm](COLLAR_LENGTH) of bore, so it stands against the wall at both ends of one. Preserve the supplied OVER length, including during any cold-kit modification.

The organizer, the bundle, the sleeve over it and four collars on the bare tails are drawn in [`/hardware/faucet-layout/faucet_assembly.py`](/hardware/faucet-layout/faucet_assembly.py), which carries the terminated end at full size and the metre and a half of straight between it and the faucet as a figure rather than a length.

### 5. Bag the sub-assembly with the under-counter plate

Lay the bundled umbilical down with the faucet at one end and the four bare tube tails + lower signal-cable end at the other. Coil the umbilical loosely (8–12" loop diameter).

The TPU gasket is already on the shank from step 2 and is not in the bag. Into the bag with the umbilical goes the one part the countertop mount still needs:

- **One SendCutSend 0.060" 316 SS under-counter plate** — the single-piece plate that slides laterally onto the dangling umbilical from below at install.

The other two stations on that wall take the customer's own runs — the tap-water run to their tee and the tether to their cylinder's regulator. Those ship made up in the install kit, each wearing its collar, `TAP` and `CO2`, from [`finish-pack-ship.md`](/hardware/assembly/finish-pack-ship.md) §6.

The customer-facing install instructions are the bound install guide in the kit ([`/hardware/install-guide/`](/hardware/install-guide/README.md)), which draws these actions and covers the opening, the cylinder, the cord and the first pour. Its packing and content contract is [`/marketing/unboxing-and-installation.md`](/marketing/unboxing-and-installation.md).

Bag, seal, label with build number and the part identifier `FAUCET-UMBILICAL-SUBASSEMBLY`, set aside for [`finish-pack-ship.md`](/hardware/assembly/finish-pack-ship.md) (TBD).

## Output condition

A bagged sub-assembly that is:

- One above-counter fixture stack with the four umbilical tubes installed
- The umbilical is **permanently attached** to the faucet assembly — the blue carbonated-water tube is connected at the Westbrass's lower upstream compression port; a separate 3/8" soda faucet tube leaves the top port through the gooseneck; the two flavor tubes and the white 4 mm D between them pass through the mounting slot, with the flat SIG-6 ribbon behind them. The separate D ends inside the common passage and drains through its round Ø4 mm underside hole. Below the counter, the four umbilical tubes share one sleeve with foam on the cold blue tube only and the fitted SIG-6 ribbon alongside.
- Three tubes terminated bare and square-cut at the +Y wall of back-top, ready for push-into-PP1208E at install
- One printed collar on each tail, below the sleeve's end — `SODA` on the blue, `FLAVOR` on each black and `OVER` on the white 4 mm run, each matched to its socket.
- On a White faucet, each flavor tube white from the printed tip to its PP0408W union inside the braid's top and black from there to the wall; the soda faucet tube white
- SIG-6 ribbon assembled and fitted at the faucet, its wall end crimped into an RJ11 6P4C plug and lying with the four bare tube tails. The plug mates the keystone jack on the +Y wall of back-top at field install. No signal conductor is cut or terminated in the field.
- TPU above-counter gasket already in place on the shank between the above-counter plate's underside and where the countertop top surface will be (installed at this bench, not in the install kit; customer never touches it)
- Retained donor washer and shank nut captive on the bare shank above the permanent blue-tube connection; the same nut is hand-tightened at field install
- **One SS under-counter plate** loose in the bag
- Labeled, sealed, ready to drop into the appliance carton at [`finish-pack-ship.md`](/hardware/assembly/finish-pack-ship.md)

## Sources
[value](NAME) texts are updated by:
- `/hardware/assembly/_faucet_and_umbilical_sync.py`
- `/hardware/cut-parts/faucet/under-counter-plate/under_counter_plate.py`

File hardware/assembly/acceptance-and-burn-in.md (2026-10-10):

# Acceptance and Burn-In

The production procedure for the bench acceptance test and multi-hour burn-in on a finished, commissioned appliance — the last sign-off step before the unit moves to [`finish-pack-ship.md`](/hardware/assembly/finish-pack-ship.md), and the bench that empties it for transit. Inputs are a chassis that has come out of [`firmware-and-commissioning.md`](/hardware/assembly/firmware-and-commissioning.md) with sensors healthy and setpoints loaded; outputs are a per-serial test log and a unit cleared to ship.

This is the first service fill after the water-filled hydro-test, draining and passivation in [`pressure-vessel.md`](/hardware/assembly/pressure-vessel.md). The carbonator is integrated dry through [`cold-core.md`](/hardware/assembly/cold-core.md) and [`refrigerant-loop.md`](/hardware/assembly/refrigerant-loop.md). Its [water-inlet jet](/hardware/assembly/water-inlet-jet.md) must have a completed fit and full-root-fusion qualification record. The bench rig represents the customer water and CO2 connections; temporary measurement instruments record the actual operating conditions.

**Firmware prerequisite:** [`src_appliance/machine.cpp`](/firmware/src_appliance/machine.cpp) implements automatic refrigeration and dispense-then-refill, including both relay outputs. The production bench mode with actuator inhibit, explicit carbonator first-fill control, burn-in timer and per-serial log download described below are not exposed by the current appliance console. Complete and commission those acceptance controls before this is a production acceptance run. Record first-unit bench measurements with their actual control method when those controls are absent; manual evidence does not sign off an unimplemented acceptance interface. This procedure does not authorize a firmware or power-policy change.

## Scope

In: a chassis fresh out of [`firmware-and-commissioning.md`](/hardware/assembly/firmware-and-commissioning.md) — powered, firmware flashed, all sensors healthy on first read (both temperature probes (DS18B20 carbonator + DS18S20 coil), four reeds on each flavor reservoir, both reeds on the carbonator, the DIGITEN flow sensor, the MQ-6), all [11](VALVE_COUNT) solenoid valves cycled through their firmware self-test, compressor + condenser fan firmware-gated together, setpoints loaded (carbonator wall [2 °C](WALL_SETPOINT) [± 2 °C](WALL_BAND), evap-coil freeze cutout [−8 °C](FREEZE_CUTOUT), compressor min-off [3 min](MIN_OFF)); a bench test rig consisting of a test-rig water source feeding the +Y wall's PP1208E 1/4" JG QC inlet, a test-rig CO2 cylinder; this unit's own Taprite 3741 primary regulator, new in its box, and its ~12 in red 1/4" LLDPE tether, which step 1 makes up, sets and connects to the ABU44 bulkhead, the in-machine secondary holding the nominal [43.5 PSI](CO2_CENTERLINE) gas feed from it; a [12 oz](GLASS_OZ) target glass, a graduated cylinder ([250 mL](CYL_MIN) or larger), a thermocouple gun or food thermometer ([0–20 °C](THERMO_RANGE) range), a stopwatch, and a refractometer if available for ratio check; two SodaStream concentrate bottles (Diet Mountain Dew + one other) primed in the flavor reservoirs via the funnel before the test sequence begins.

Out: a unit that has passed every step of the functional acceptance test below (first water fill of the carbonator without leak; CO2 and carbonator pressures measured through refill and hold, PRV does not weep, the dedicated faucet drain stays dry; refill completes and restarts; first and successive carbonated-water dispenses ~[12 oz](GLASS_OZ) at ≤ [~6 °C](DISP_TEMP_MAX) with the agreed strong-carbonation result; first flavor A and flavor B dispenses at the target ratio with measured pump output; clean cycle through both channels; air-purge cycle; all level-sensing transitions observed correctly) and a multi-hour burn-in (with periodic dispenses on a timer, watching compressor cycle count, watching for nuisance freeze-protect trips, watching for leaks, watching for MQ-6 trips). The unit's primary regulator leaves acceptance set to [75 PSI](CO2_PRIMARY_SET), its jam nut locked and paint-marked, with the red tether in its outlet; it ships at that setting and the customer sets nothing. Per-serial test log archived.

Not in scope: cosmetic inspection, nameplate verification, packaging — all in [`finish-pack-ship.md`](/hardware/assembly/finish-pack-ship.md). Customer-side install commissioning (running the unit on the customer's tap-water + CO2 bottle for the first time in their kitchen) is a separate procedure, not part of factory acceptance.
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

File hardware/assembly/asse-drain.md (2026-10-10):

# ASSE 1022 faucet drain

Simply having a 1022 already puts us ahead of most of these products. A 1022 that vents into the bowl at the faucet would be the only home arrangement I've found where the vent's discharge is defined, drained and visible.

The Multiplex 19-0897 vent discharges through a separate white
[4](DRAIN_OD) mm OD / [2.5](DRAIN_ID) mm ID LLDPE tube. Its square-cut end is
inside the faucet tip's unsealed pocket. A round Ø4 mm underside opening
provides a visible major-fault drip over the sink bowl. Plain printed guide
walls carry the continuous beverage tubes and insulated conductors; no
additional drain gasket or bung is fitted. Incidental escape into the faucet
housing is accepted during that fault.

## Parts
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

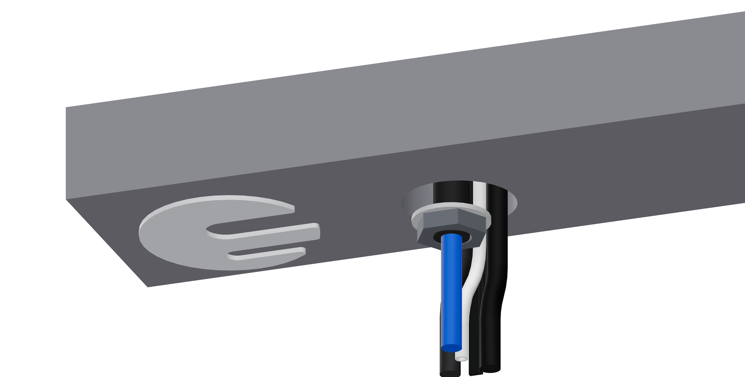
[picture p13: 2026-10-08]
hardware/install-guide/assets/steps/mount-under-slide-clean.png

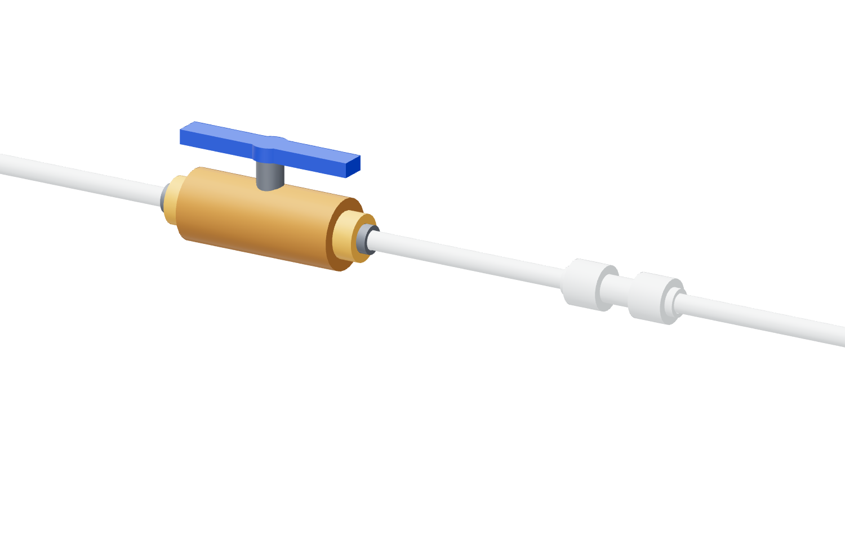
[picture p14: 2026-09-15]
hardware/install-guide/assets/kitchen-push.png

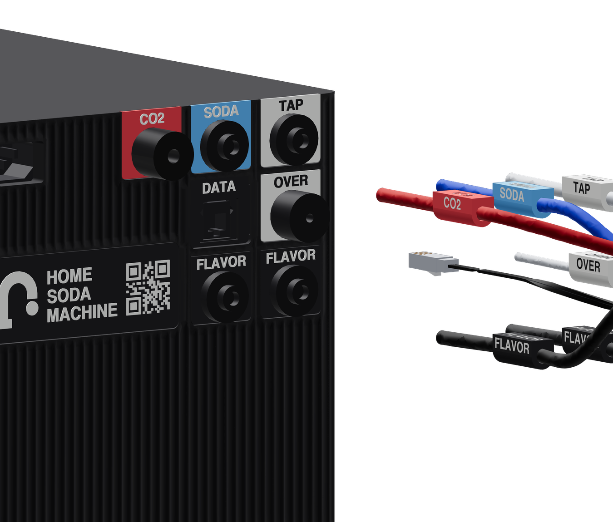
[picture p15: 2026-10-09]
hardware/install-guide/assets/reference/drain-connect-rear-open.png

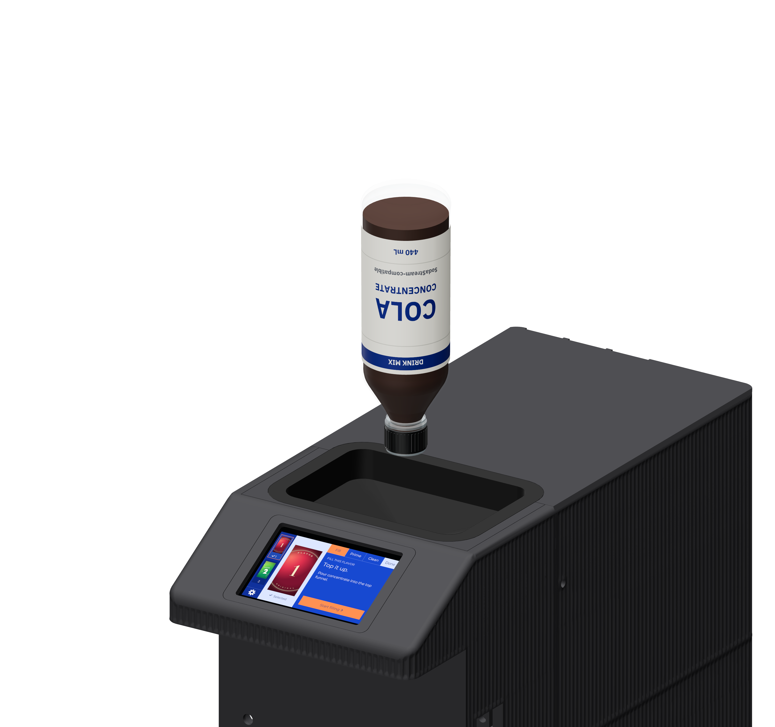
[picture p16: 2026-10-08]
hardware/install-guide/assets/steps/fill-ready.png

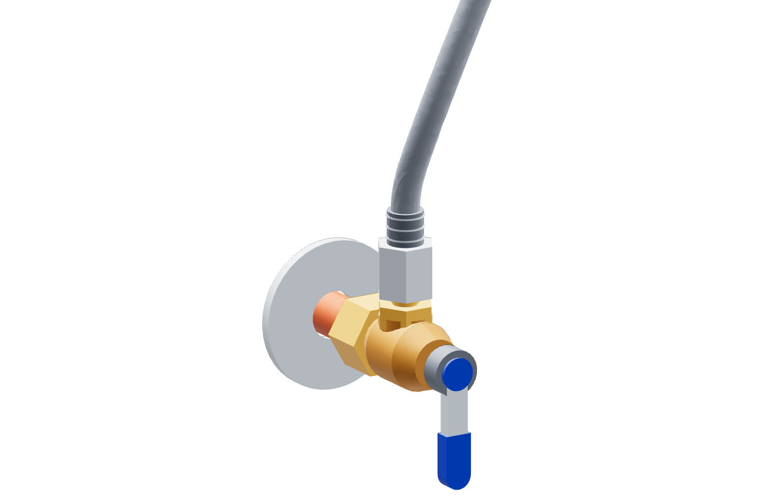
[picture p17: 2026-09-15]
hardware/install-guide/assets/kitchen-hose.png

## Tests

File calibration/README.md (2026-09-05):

# calibration

Working calibration between Derek and the agents in this repo.
[`Principle.md`](Principle.md) distills [`principle/You.md`](principle/You.md) and
[`principle/Framing.md`](principle/Framing.md) — the rooms where it happened. Any rule is
better encoded as an example; the desire to write one marks a gap in the repo, and the fix
lives there. [`principle/Provenance.md`](principle/Provenance.md) is the third room: the
geometry read as a record of who decided what, and Derek's word first.

`block-residue.sh` in `~/Developer/claude-code-setup/hooks/` reads `Principle.md` and the two
rooms it distills at these paths.

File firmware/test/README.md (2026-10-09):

# Firmware tests

The native suite holds machine policy that does not need, open, reset, or drive a board:

```bash
pio test -e native
```

`test_front_ui_policy` checks Stop-only operation locks from queued Start through completion,
prime cancellation exits, remote flavor changes on flavor versus machine pages, and stale
sensor readings including clock wrap.
`test_flavor_selection` checks first-install adoption, established-main-board authority,
absolute/idempotent selection, corrupt storage, and failed-write retry state.
`test_machine_policy` checks the canonical V-A–V-K operation plans, the three-valve ceiling,
the dispense/refill exclusion, every possible off-before-on valve-mask transition, the
prime/timed-pump deadlines shared with the J9 protocol, the funnel fill's plan, its
draw-time budget against the slowest rated head, and its full-reed-before-clock ending, and
the clean cycle's two steps per channel, its full-reed and empty-reed-plus-tail endings, the
sum of what is left of a cycle, and its wire contract, the reservoir gauge's reading of one
float passing four reeds up through a fill and down through a draw, and the air cycles' steps — the dry
sweep of both channels that draws on no reservoir, and the purge that airs one and draws it
out. It also checks that Prime queries renew the main-board lease while giving queued J9
announcements a turn, that snapshots stay fresh through a full queue at dark-display polling
speed, and that discovery queries and direct hold/stop/cancel replies retain priority.
`test_machine_prime` runs the production machine arbiter and expander driver with host
GPIO, clock and I2C fakes. It checks wet Prime's reservoir dispense pairs, pump-before-valve
stop ordering including expander faults, token/session retries and competing displays,
cancel/disconnect/heartbeat/lease/ceiling endings, gas and I/O admission, the falling
reservoir gauge, refill/pour exclusion and fan preservation. Console motor checks and the
self-test remain individual motor loads. These tests do not establish physical wet operation.
`test_pour_policy` checks the pour's cycle timing at 1:20, 1:6 and 1:24, the clamps either
side of the flow reading and the floor and ceiling on the two phases, the sequence one pour
walks — valves and pump opening on the first reading, each cycle's timing taken from the
average over the last, a cooldown that holds the path open when flow returns inside it and
closes it when nothing does — the 120 s ceiling a meter that never stops pulsing runs into, and
the sample period and pulse counts the meter is read through. `test_pcba_expanders` checks the
logical-to-physical valve map, safe MCP23017 initialization, active-low reed decoding,
cross-expander break-before-make writes, and fail-park behavior. `test_sound_policy` walks
every volume against every quiet ceiling at every hour including no clock at all, and holds
the gas alarm at full through all of them; it also checks the quiet window's midnight wrap,
its empty case, and that the duty conversion is linear in amplitude rather than in duty.
`test_echo_policy` checks that a frame the main board sent comes back and is swallowed whole,
that a collision abandons the outstanding echo instead of eating the far end's next frame,
and that the ring wraps under sustained traffic and holds a whole stuffed J9 frame. They run on the build host
and are safe with every USB device connected. `test_weld_rotator_policy` checks the purchased
20T:90T drive ratio, speed envelope, exact 380-degree lap count, boot-held pedal lockout,
deadman release, and jog/lap state transitions.

Board builds remain separate because they compile different source trees:

```bash
pio run -e appliance
pio run -e esp32s3_front
pio run -e esp32s3_faucet
pio run -e pcba_bench
pio run -e weld_rotator
```

Building does not open a serial port. Uploading and monitoring do; name the port whenever
more than one board is connected (`tools/boards.py` prints the exact commands).

With the working main board and enclosure display connected, the default live check only observes
the display, touch controller, J9 link, and synchronized/durable flavor state through the
display's native USB port. The optional checks are deliberately explicit: `--animation`
opens the reusable operation lock long enough to measure it; `--toggle` selects the other
flavor, proves main board synchronization and persistence, and restores it; `--prime a|b`
actuates that pump for about one second through the same handlers the glass uses and always
posts a stop request. Each check restores the page, idle rung and lock state it found.

```bash
~/.platformio/penv/bin/python tools/firmware_live_check.py
~/.platformio/penv/bin/python tools/firmware_live_check.py --animation
~/.platformio/penv/bin/python tools/firmware_live_check.py --toggle
~/.platformio/penv/bin/python tools/firmware_live_check.py --prime b
```

With the faucet display connected to J3 and its native USB connected, the faucet check never
drives an actuator. Its default mode proves convergence, both persistence states, request
latency and loop/link-service high-water marks. `--toggle` explicitly selects the other
flavor, waits for both stores, and restores the original selection; the main board makes one
tick for each of those two user-path selections.

```bash
~/.platformio/penv/bin/python tools/firmware_faucet_check.py
~/.platformio/penv/bin/python tools/firmware_faucet_check.py --toggle
```

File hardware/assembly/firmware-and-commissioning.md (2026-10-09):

# Firmware and Commissioning

The production procedure for first-time firmware flash and DC-side commissioning of a fully wired chassis. Takes the never-powered output of [`wiring.md`](/hardware/assembly/wiring.md) — AC and DC continuity checks already passed — through three MCU flashes, a controlled first power-on under PSU, a sensor-health walkthrough, a valve self-test, and a brief firmware-driven compressor cycle confirming relay #1 switches the AC leg. Stops short of any test that requires water or CO2 — those live in [`acceptance-and-burn-in.md`](/hardware/assembly/acceptance-and-burn-in.md).

Customer-side firmware binding (Wi-Fi credentials, cloud pairing, app association, per-customer ratio tuning) is **not** done here. Firmware ships with factory defaults; the iOS/Android app handles binding at first install. This procedure ends with a unit that boots clean, self-tests clean, and is ready to take water + CO2 in the next station.

Design intent and runtime behavior live in [`/hardware/README.md`](/hardware/README.md) "Refrigeration" + "Carbonation". Pin assignments and wiring topology live in [`/hardware/wiring/esp32-pinout.mmd`](/hardware/wiring/esp32-pinout.mmd) and [`/hardware/wiring/valve-control.mmd`](/hardware/wiring/valve-control.mmd). The PlatformIO environment names live at the repo root in [`/platformio.ini`](/platformio.ini).

## Scope

In: a fully wired chassis fresh out of [`wiring.md`](/hardware/assembly/wiring.md) — AC and DC continuity checks passed, never powered. The flash tooling — a USB-C cable (the main board's J14 programming port and both displays present USB-C), PlatformIO on the build host, and the firmware source tree at `/firmware/` configured per [`/platformio.ini`](/platformio.ini). A multimeter for runtime DC-rail spot checks. A serial console (`pio device monitor`) for log capture.

Out:

- All three MCUs — the main board's ESP32-WROOM, the 4.3" enclosure display, the 1.47" faucet display — flashed with the current firmware on `main`.
- First DC power-on under PSU control succeeds with no smoke, no breaker trip, no thermal-fuse open.
- Sensor health passes: both 1-wire probes addressed on the bus — one DS18B20 (carbonator, family 0x28) + one DS18S20 (coil, family 0x10) — and reporting within [±2 °C](AMBIENT_TOL) of room ambient; all [10](REEDS_TOTAL) reed switches ([2](REEDS_CARB) carbonator + [4](REEDS_PER_RSVR) per flavor reservoir × [2](RSVR_COUNT) reservoirs) settled to their no-magnet "empty" baseline; the DIGITEN flow meter ticks pulses when its impeller is rotated by hand; the MQ-6 hydrocarbon sensor in the floor strip down the refrigeration bay's −X wall has reached operating temperature and reads its clean-air baseline.
- Both MCP23017 GPIO expanders ACK on the I²C bus at [0x20](MCP_VALVES) and [0x21](MCP_RESERVOIRS), with the DS3231 RTC at [0x68](RTC_ADDR) also responsive.
- Valve self-test pass: each of the [11](VALVE_COUNT) Beduan solenoids clicks once with audible / visual confirmation, and both Kamoer peristaltic pumps spin briefly under DRV8870 drive.
- Relay #1 verified switching the compressor's AC leg under a deliberate firmware override: the suction-line probe (the DS18S20, family 0x10) reads a few degrees lower within a couple of minutes of the override starting (running dry, no water in the carbonator), confirming the relay is making AND that the DS18S20 is physically mounted on the suction line (its identity among the two probes is already fixed by family code, not by this test).
- Firmware setpoints loaded with factory defaults: **carbonator target [2 °C](TANK_TARGET), hysteresis [±2 °C](HYSTERESIS)** (compressor off at [2 °C](COMP_OFF_TEMP), on at [4 °C](COMP_ON_TEMP)), **freeze-protect cutoff [−8 °C](FREEZE_CUTOFF)** on the suction-line probe, **[3-minute](MIN_OFF_TIME) minimum off-time** for the compressor start capacitor, refill threshold on the carbonator's low-level reed.
- Per-serial commissioning log archived (sensor readings, I²C ACK list, valve click confirmation, compressor-cycle suction-line ΔT).

Not in scope: any acceptance test that requires water or CO2 (that's [`acceptance-and-burn-in.md`](/hardware/assembly/acceptance-and-burn-in.md)); customer-side firmware binding via the iOS/Android app at install (post-shipping); the over-the-air firmware-update flow (not in scope for first-unit shipping).

## Inputs per appliance

| Item | Source / spec | Notes |
|---|---|---|
| Wired chassis | Output of [`wiring.md`](/hardware/assembly/wiring.md) | Never powered. AC + DC continuity checks passed. Compressor bolted down and grounded; donor terminal cover intact, unmodified, and securely retained; factory lead exit undamaged. |
| Firmware source tree | [`/firmware/`](/firmware/) on the build host, current `main` | PlatformIO project; envs `appliance`, `esp32s3_front`, `esp32s3_faucet` (see [`/platformio.ini`](/platformio.ini) and [`/firmware/README.md`](/firmware/README.md)). The `appliance` tree is an Open item below. |
| PlatformIO | On the build host | `pio run -e <env> -t upload` builds and flashes. One board on USB at a time, or name the port — PlatformIO picks the S3 otherwise and esptool leaves that panel dark. |
| USB-C cable | Fits the main board's J14, the 4.3B, and the 1.47" faucet display | Build-bench stock; not per-unit consumable. |
| Multimeter | Build-bench stock | DC-rail spot checks at [12 V](RAIL_12V) (J10 clamps), [5 V](RAIL_5V) + [3.3 V](RAIL_33V) (connector pins). |
| Serial monitor | `pio device monitor -e appliance` (115200 baud) | Captures the ESP32 boot log + structured commissioning output for the per-serial archive. |
| Commissioning-log template | TBD — see Open items | Per-unit serial + sensor readings + I²C ACK list + valve confirmation + suction-line ΔT during the relay #1 verification. |

Tooling (per-unit-amortized): one build-bench station with a PSU-controlled outlet feeding the C14 input, a current meter inline with the PSU output for the 12 V rail, and a USB hub on the bench host.

## Procedure

### 1. Verify wiring-out inputs

Before any power, walk the chassis once against [`wiring.md`](/hardware/assembly/wiring.md) output condition: compressor bolted down and grounded; donor moulded cover intact, unmodified, and securely retained over the terminal/PTC assembly; factory lead exit undamaged; electronics bay populated and fastened; ground bus continuous from C14 earth pin to every exposed-metal bond point; all JST XH looms seated on their labeled wafers (J4 vs J7 by loom label per [`cable-assemblies.md`](/hardware/assembly/cable-assemblies.md)); the J10 polarity verified (`V12` east / `GND` west).

This is a *re-look*, not a re-test — the AC and DC continuity sign-offs from `wiring.md` are not repeated here. If anything in the electronics bay has moved since `wiring.md` signed off, return the unit there before continuing.

### 2. First DC power-on under PSU control

Power the C14 inlet through a bench PSU-controlled outlet, not direct wall power. The Teyleten relay #1 must remain de-energized for this step — the firmware boots into "all off" by default, but the PSU-controlled outlet is the hardware backstop.

When mains reaches the C14 inlet, AC propagates directly through the distribution block to the PSU primary — the AC path is C14 inlet → AC distribution block → PSU, with no device in series (ground-fault protection is deferred, see [/future/pie-in-the-sky/gfci.md](/future/pie-in-the-sky/gfci.md)). If no DC rails come up in the next sub-step, check AC-1 wiring back to the C14 inlet and the distribution-block landings.

Bring up in this order, verifying each rail with the multimeter before the next:

1. PSU output enabled — verify **[12 V](RAIL_12V)** at the distribution-block test point (PSU is the Mean Well IRM-90-12ST, see [`/hardware/wiring/ac-wiring-schedule.md`](/hardware/wiring/ac-wiring-schedule.md) run DC-1). Expected ~[12 V](RAIL_12V) [± 0.2 V](RAIL_12V_TOL) at no load.
2. **[5 V](RAIL_5V) rail** at a `V5` connector pin (J4 or J5) — expected [5 V](RAIL_5V) [± 0.1 V](RAIL_5V_TOL). The rail is the main board's K7805 buck (U10) off the J10 12 V inlet; it feeds the 3.3 V LDO, the relay-module VCC (via J5), the flow meter, and the MQ-6 heater. Power tree: [`/hardware/wiring/power.mmd`](/hardware/wiring/power.mmd).
3. **[3.3 V](RAIL_33V) rail** at a `3V3` connector pin (J4 or J8) — expected [3.3 V](RAIL_33V) [± 0.05 V](RAIL_33V_TOL). The rail is the main board's AMS1117 LDO (U9) off the 5 V buck; it feeds the WROOM, both MCP23017s, the DS3231, the RS485 transceiver, and the on-board pull-ups.

Under *full* logic load — all MCUs flashed and both display backlights on (revisit after step 6) — the 5 V rail holds tolerance.

If any rail is out of tolerance, kill the PSU and return the unit to `wiring.md`. Do **not** energize the AC side (compressor + fan) at this step — relay #1 stays de-energized until step 8.

Spot-check current draw at the PSU: cold idle sits low — the WROOM's boot-ROM idle, the main board's rail LEDs, and the relay-module opto quiescent draw tens of mA; the relay coils are de-energized, no valves are driven, no pumps.

### 3. Flash the base ESP32 (main board)

Plug the USB-C cable into the main board's J14, flush on the west edge of the main board. The on-board CH340C (U13) enumerates as a USB CDC port on the build host, with auto-reset driving EN/IO0 into download mode.

From the repo root:

```
pio run -e appliance -t upload
```

Per [`/platformio.ini`](/platformio.ini). Expected outcome: build succeeds, upload reaches 100 %, ESP32 resets, the serial monitor at 115200 baud shows the firmware boot banner with the `fw_version.h` build ID.

`src_appliance/` boots to that banner with every actuator parked. What it runs is in its [README](/firmware/src_appliance/README.md) "What runs today"; what has not yet answered on real hardware is the Open item below.

### 4. Flash the ESP32-S3 enclosure display

Plug the USB-C cable into the ESP32-S3-Touch-LCD-4.3B (the enclosure display, let into the sloped plane of `enclosure-front-top`'s rounded top-front arris per [`/hardware/printed-parts/enclosure/enclosure/README.md`](/hardware/printed-parts/enclosure/enclosure/README.md); its SIG-7 RS485 link to the main board's J9 lands at [`wiring.md`](/hardware/assembly/wiring.md)). It enumerates as a native USB-CDC device — the build flag `ARDUINO_USB_CDC_ON_BOOT=1` in `[env:esp32s3_front]` brings the CDC port up immediately on boot.

```
pio run -e esp32s3_front -t upload
```

Confirm the LVGL splash renders on the 800×480 panel after reset.

### 5. Flash the ESP32-S3 faucet display

Plug the USB-C cable into the 1.47" faucet display at the end of the gooseneck. Same native USB-CDC boot as the 4.3B.

```
pio run -e esp32s3_faucet -t upload
```

Confirm the flavor UI renders after reset. The touch-toggle check lands in step 6, once the base ESP32 is broadcasting flavor frames over the SIG-6 UART.

### 6. Sensor health walkthrough

With both MCUs running their default firmware, open the serial monitor on the ESP32:

```
pio device monitor -e appliance
```

The default firmware periodically prints a sensor-health frame. Step through each line:

- **I²C scan** — expect ACKs at [0x20](MCP_VALVES) (MCP23017: 8 valves + Reservoir A reeds), [0x21](MCP_RESERVOIRS) (MCP23017: 3 valves + condenser-fan driver bit + Reservoir B reeds + carbonator reeds), and [0x68](RTC_ADDR) (DS3231 RTC). All three are on the main board, so a missing ACK is a main-board fault.
- **1-wire temperature bus** — expect exactly two devices on the bus on [GPIO 26](GPIO_ONEWIRE): one DS18B20 (family `0x28`, carbonator-wall) and one DS18S20 (family `0x10`, suction-line). Firmware routes each reading by family code, so the `0x28`/`0x10` split is itself the pass criterion — two same-family devices, or a missing family, is a wrong-part or mounting error. Both should report within [±2 °C](AMBIENT_TOL) of room ambient with the compressor de-energized. If only one address enumerates, suspect a parasitic-power miswire in the J4 loom (the [4.7 kΩ](ONEWIRE_PULLUP) pull-up R9 is on the main board).
- **Carbonator reeds** (MCP23017 [0x21 PB4](REED_LOW) low, [0x21 PB5](REED_HIGH) high) — both on the MCP internal pull-up, both reading high (no magnet present, no float installed yet). Bring a small bench magnet near each reed in turn and confirm it pulls low.
- **Reservoir reeds** — all 8 (Reservoir A on MCP23017 [0x20](MCP_VALVES) PB[0:3], Reservoir B on [0x21](MCP_RESERVOIRS) PB[0:3]) reading their no-magnet baseline. Architecture and calibration in [`/hardware/printed-parts/cold-core/reservoir/level-sensing.md`](/hardware/printed-parts/cold-core/reservoir/level-sensing.md). Same bench-magnet check per reed.
- **DIGITEN flow meter** ([GPIO 25](GPIO_FLOW)) — manually rotate the impeller with a clean implement; expect a pulse count increment per rotation in the serial output.
- **Faucet display toggle** — touch the 1.47" faucet display; the selected flavor switches and the base ESP32 logs the change over the SIG-6 UART.
- **MQ-6 hydrocarbon sensor** — needs ~60 s warm-up to reach operating temperature. After warm-up, expect a clean-air baseline reading on its analog input (verify the bench air is free of solvents or LPG nearby — wave clean air across the sensor or move the chassis briefly to a clean-air environment if needed). Architecture: the MQ-6 stands on edge low in the refrigeration bay, in the open floor strip down the -X wall beside the compressor, mesh horizontal and looking aft along that strip (the bare sensor's orientation is unconstrained per the Winsen datasheet; what the position is for is height -- the bay's floor is one connected pool that every dominant brazed-joint leak site drains into, and dense R-600a spreads over the slab as one layer) — the hardware-only backstop to the firmware-controlled cutoffs ([`refrigerant-loop.md`](/hardware/assembly/refrigerant-loop.md) "Safety").

Record each reading in the per-serial commissioning log. Any out-of-bounds reading at this step blocks the unit from proceeding to step 7.

### 7. Valve and peristaltic-pump self-test

The firmware exposes a self-test command over the serial console that walks each of the [11](VALVE_COUNT) Beduan solenoids individually and then spins each peristaltic pump briefly. Trigger it from the monitor prompt.

- **Solenoid sequence** — the firmware drives each valve output in turn: [0x20](MCP_VALVES) PA through TBD62083 U4 (V-A through V-H), [0x21](MCP_RESERVOIRS) PA[6:7] through U5 (V-I, V-J), and [0x21](MCP_RESERVOIRS) PA5 through U5 channel 3 to `J2.OUT3` (V-K); see [`/hardware/wiring/valve-control.mmd`](/hardware/wiring/valve-control.mmd). Each coil energizes for ~250 ms then releases. Expected: [11](VALVE_COUNT) distinct clicks. Listen for stuck-on coils (no audible release click). Ten clicks come from the manifold pack; V-K's comes from its cradle on the cold core's crown, at the far end of the DC-9 run.
- **Condenser fan** — driven by MCP23017 [0x21](MCP_RESERVOIRS) PA3 through TBD62083 U5 channel 5. The self-test gives the fan a brief 1-second run. Expected: audible spin-up of the [12 V](RAIL_12V) DC brushless axial mounted to the enclosure side wall, then coast-down.
- **Peristaltic pumps** — driven by the on-board DRV8870 H-bridges (U11/U12) through J13. The self-test spins Pump A forward for ~1 s, then Pump B. Expected: each silicone tube head rotates visibly. No flavor is loaded yet; the head turns dry.

Any failure here is loom wiring, a device fault, or a board fault. Resolve and re-run before continuing.

### 8. Relay #1 compressor-cycle smoke test

This is the only step that energizes the AC side. The carbonator is **empty** (no water, no CO2) — the run is brief and intentional, just enough to confirm the AC leg switches and the suction line cools.

Trigger the firmware-override compressor-on command at the serial console. The firmware drops the [3-minute](MIN_OFF_TIME) minimum-off-time guard for this command only and asserts [GPIO 19](GPIO_RELAY1); the on-board gas→compressor interlock (U15) passes it to J5 only while the MQ-6 reads clear — a missing or cold gas sensor holds relay #1 open (step 6's warm-up is a prerequisite). The relay energizes and closes the AC leg through the SF76E into the verified hot side of the compressor assembly's factory-external electrical interface; the terminal/PTC assembly remains under the donor cover.

Watch for, in order:

1. **PSU current bump** at the inline meter — the relay coil pulls ~70 mA additional through the 5 V rail; small but visible.
2. **Compressor audible start** — the PTC start relay clicks and the hermetic compressor's motor spins up. The clip-on overload should not trip on a healthy compressor; if the overload opens, kill the override immediately and return to [`refrigerant-loop.md`](/hardware/assembly/refrigerant-loop.md) for diagnosis.
3. **Current draw at the AC side** — within nameplate (a couple of amps RMS on the 120 VAC leg for the harvested ice-maker compressor). Verify with a clamp meter on the switched-hot run AC-4 if the build bench has one.
4. **Suction-line probe (DS18S20) temperature** — drops a few degrees within a couple of minutes. The cold core has no water to absorb heat, so the suction line cools faster than it will in normal operation; this is the intended diagnostic, not normal-operation behavior.

After 30–60 seconds, send the firmware-override compressor-off command. The compressor de-energizes, the suction-line probe begins warming back toward ambient, and the [3-minute](MIN_OFF_TIME) minimum off-time guard re-arms.

This is **not** a refrigeration commissioning step. Full thermal cycling under water load happens at [`acceptance-and-burn-in.md`](/hardware/assembly/acceptance-and-burn-in.md). All this step proves is: (a) relay #1 makes the AC leg, (b) the compressor draws nameplate current, (c) the suction-line probe is on the right probe.

### 9. Verify setpoints loaded

`status` on the main board's console prints the loaded setpoints as the loop
is standing in them. Expected:

- Carbonator target: **[2 °C](TANK_TARGET)**
- Hysteresis: **[±2 °C](HYSTERESIS)** (compressor on at [4 °C](COMP_ON_TEMP), off at [2 °C](COMP_OFF_TEMP))
- Freeze-protect cutoff: **[−8 °C](FREEZE_CUTOFF)** on the suction-line probe, clearing at **[−5 °C](FREEZE_RECOVER)**
- Compressor minimum off-time: **[3 min](MIN_OFF_TIME_BARE)**; minimum on-time **[60 s](MIN_ON_TIME)**
- A probe silent for **[30 s](READING_STALE)** is no reading, and parks the compressor
- Carbonator refill threshold: low-level reed (MCP23017 [0x21 PB4](REED_LOW))
- Sound volume: **70%**, quiet hours **off** (`volume` / `quiet` on the main board's console)

Every figure above is read out of [`cold_policy.h`](/firmware/lib/machine_policy/cold_policy.h)
when this page is generated, so the number the factory confirms and the number
the compressor obeys are one number. They are baked into the firmware on `main`
as factory defaults; no per-unit setting is required here. Customer-side tuning (ratio adjust, Wi-Fi binding, cloud pairing) happens through the iOS/Android app post-install.

Then query the three limits the hardware imposes. Each one is a part's rating, and the firmware is the only thing holding the machine inside it:

- Valves energized at once: **at most [3](MAX_VALVES)**. Eight coils on MANIFOLD A cross J1's `COM` contact rating and land in one TBD62083 — [`/hardware/wiring/ac-wiring-schedule.md`](/hardware/wiring/ac-wiring-schedule.md) "Solenoid COM current budget".
- Refill gated on the dispense window: **relay #2 ([GPIO 2](GPIO_RELAY2)) de-energized while a dispense is open**. The main board peaks at [3.33 A](BOARD_PEAK_A) and the G Ganen is budgeted at [5 A](DIAPHRAGM_A) on one [6.7 A](PSU_MAX_A) supply — [8.32 A](COINCIDENT_A) if they overlap. The low reed asserts mid-pour, so the refill it queues waits ([`acceptance-and-burn-in.md`](/hardware/assembly/acceptance-and-burn-in.md) step 5).
- Reed pull-ups: **`GPPU` written on both MCP23017s**. No loom carries a resistor and the main board pulls none of these inputs ([`/hardware/pcb/pcba/pcba.tsx`](/hardware/pcb/pcba/pcba.tsx)), so a reed with no pull-up floats and step 6's baselines are meaningless.

A unit that walks step 7 and passes step 6 can still be failing all three — nothing here reads them off behavior. The query is the check, and step 7's own walk goes through the state machine holding them (Open item 3).

Then confirm the one safety property that lives entirely in firmware and has no hardware behind it: **the gas alarm cannot be silenced.** Volume, mute and quiet hours reach every sound the machine makes except that one, and a unit that let a customer mute a refrigerant-leak alarm would ship a defect nothing downstream would catch. Set the clock first, since quiet hours will not engage without one:

```
rtc set <YYYY-MM-DD> <HH:MM:SS>
volume 0
sound tick
sound alarm
sound stop
volume 70
```

**Pass:** `sound tick` reports `silenced, so nothing will be heard` and the main board stays silent; `sound alarm` reports `alarm at 100%` and the transducer sounds at full volume. **Fail:** either the tick is audible at volume 0, or the alarm is not — do not ship the unit; the exemption is `SND_F_UNSILENCEABLE` in [`/firmware/lib/sound/sound.h`](/firmware/lib/sound/sound.h).

`sound list` prints what every sound would play at right now, which is the fastest read on whether volume and quiet hours are where this step expects them. U15 holds the compressor off the same MQ-6 signal in hardware with no firmware in the path — that interlock is step 8's, and it is a different check from this one.

### 10. Archive the per-serial commissioning log

Snapshot the serial-monitor output from steps 6–9 into a per-serial log file. At minimum capture: firmware build ID (`fw_version.h`), I²C ACK list, 1-wire probe addresses + family codes (0x28 carbonator / 0x10 coil) + first-read temperatures, all [10](REEDS_TOTAL) reed baselines, flow-meter pulse count, MQ-6 baseline, valve self-test pass/fail per channel, suction-line probe temperatures before/during/after the relay #1 verification, the DS3231 time as set, and the volume-0 alarm check from step 9.

Where this log lives — local file under `/commissioning/<serial>/`, uploaded to cloud, both — is an Open item below. Working position: keep the file locally on the build host until that decision lands.
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

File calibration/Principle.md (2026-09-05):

---

# User

---

@"/Users/derekbredensteiner/Developer/homesodamachine/calibration/principle/You.md" @"/Users/derekbredensteiner/Developer/homesodamachine/calibration/principle/Framing.md"
Please distill what "Framing" refers to as "The You.md Principle".

Please explain it completely to a naive reader that has not seen either of these documents.

You must read both of these documents to do so.

---

# Assistant

---

Stated directly: **any rule is better encoded as an example.**

It came out of a recurring pattern. Agents working in the owner's repo would, at some point, want to write a memory file or a rule — "always do X," "don't do Y." The owner noticed that the *desire* to write the rule almost always signaled something real missing, but the rule itself almost never fixed it. The fix lived in the artifact: change the code, the doc, the file structure — until the thing being written-about *demonstrated* the lesson without needing the lesson stated.

**Why examples beat rules:**

- A rule is a proposition the reader accepts and tries to apply by inference. An example is a thing the reader absorbs by reading directly. Texture transfers; directives don't.
- Future readers — other agents, other people, the author six months later — learn more consistently from a worked example than from an abstracted directive.
- A rule, once written, freezes a snapshot and substitutes a stored proposition for the live process the principle was actually about.
- Writing the principle is itself an instance of practicing it. A rule that says "prefer examples" is self-undermining; an artifact that *just is* an example carries no contradiction.

**What Framing.md extends:**

Explanations aren't only less effective than examples — they can actively mislead. A reader who finds an explanation tends to assume it is the *correct* explanation and stops looking. A docstring's "we chose X over Y, Z, W" reads as the complete design space, so the reader carefully studies the wrong map and never reaches the constraint that actually drove the design.

This is **residue** — backwards-facing spike strip, invisible to the author who wrote it from the safe direction (the direction where the live alternatives were already known). Distinct from **clutter**, which only wastes attention. Clutter is the natural shape of any road; you fix it as you encounter it. Residue redirects attention at the level of premise, and more attention can't escape misdirection that's structural.

So the discipline isn't "write less prose." It's "write nothing that the reader will mistake for the design space if it isn't." Motion-oriented description, terse noun-phrases, and pointers to upstream docs do the work that justification blocks pretend to do but actively prevent.

**The honest limit:**

Example sometimes fails. When the artifact has demonstrated the lesson and agents still miss it across many runs, a stated rule earns its place as a compromise. A CLAUDE.md section that names what not to write, or a tool-call hook that mechanically blocks the wrong shape, can catch at the entrance what the example down the path didn't prevent. The compromise knows it is one and stays small.

**The shape of the discipline:**

1. Notice when you want to write a rule.
2. Treat the desire as a signal that something is missing somewhere in the artifact.
3. Find where the gap lives and fix it there — make the thing self-describing.
4. If the example has already been tested and failed, a stated rule or mechanical hook is the compromise of last resort.

---

# User

---

Hm, okay. Fair enough. Now, what is the one thing all of these conversations are trying to prevent, that they are failing to teach by example?

Hint, it is something that is only present in the examples by its absence.

---

# Assistant

---

**The thing being prevented: the author saying anything beyond what is.**

Every cleaned example describes only the current state of a thing. The plate description shows install motion. The print log records observed settings and direct quotes. CLAUDE.md describes the appliance. None of them say what was, what will be, what could have been, what should be done, why this and not that, what the reader should think.

Every form the bad versions take is a form of stepping outside present-indicative description:
- Justification → why it is this way
- Defense → what alternatives were rejected
- Decision narrative → how it came to be
- Effort estimate → what will happen
- Hedge → what the reader might think
- Memory write → what the lesson is for future situations
- Extracted rule → what should be done in similar cases
- Comment on code → what the code means
- "Designs ruled out" → what was considered

All of these are the author going outside what is.

**What's only present by absence:** in each example there is a conspicuous empty space where the going-beyond would have lived. A careful reader can see "this docstring refrains from explaining why." A naive reader sees just a description and doesn't notice the negative space. The teaching is in the empty room.

**Why agents fail to learn this from absence:** the going-beyond is invisible to them as a category. To the agent, justifying a design IS writing a design doc; predicting effort IS answering a planning question; extracting a rule IS being helpful; saving a memory IS preserving context. The "extra" isn't perceived as extra — it's perceived as the work itself. So the agent reads the bare example through the impulse the example is trying to suppress, and registers nothing.

**Why the rule strains and the hook works:** the rule "describe only what is" itself goes beyond what is — it's prescriptive, future-oriented, addressed to a not-yet-present reader. It cannot demonstrate itself; it can only state itself. The hook makes no claim and tells no story; it intercepts the impulse at the moment of expression and forces the agent to look at what they were about to write. The rule and the hook are both compromises with the failure of teaching-by-absence; the hook compromises less because it doesn't have to go beyond what is to do its work.

---

## Editor's note

This doc is a distillation of two conversations — `principle/You.md` and `principle/Framing.md` — where the calibration happened live. It is the compromise of last resort it describes: a stated rule for the case where the example alone has been tested and failed. The teaching is in the source conversations, not here.

If you arrived here from a hook because you were about to write a justification, defense, decision narrative, or comment on code: read `principle/You.md` and `principle/Framing.md` in full before you remove what you wrote. Don't mistake this doc for the lesson. It is the orientation. The lesson is in the rooms it summarizes.

**2026-09-05.** The memory-write hook is gone. Blocking memory did not remove what agents wanted to write. It moved it into the repo as prose, where an agent's reading of Derek reads in his voice, and later agents defended it against him. Memory is where provenance and an agent's own reasoning go now; the repo stays what is. The room is `principle/Provenance.md`. The earlier unblocking is in `principle/You.md`, where Derek says the problem was never the memory write itself.

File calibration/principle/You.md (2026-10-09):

---

# User

---

I didn't like Opus 4.7 at first.

For the most part, it seemed just like 4.6 ... except there were a few times I was surprised at its laziness digging into something.

I was surprised, because with 4.6 (and really, for many many iterations prior) I had gotten used to skimming responses, and just skipping to the end, and really I wasn't missing anything.

And so it did not occur to me, until it happened several times (perhaps a week into 4.7 being a forced default for a while in the desktop app, with 4.6 unavailable), that I noticed 4.7 was actually telling me about the laziness. It was up front about it, in the long winded earlier parts of the responses I skim through.

And so after getting used to it, and getting used to how 4.7 "discloses" its laziness, I have found it is actually quite capable of not being that lazy when called out on it, or, rather, when I clarify, "no I really do expect you to follow all of those threads" and the response is always "understood", and it seems so far that is indeed "understood".

The way such laziness is manifested, and disclosed, can be intricate and complex - it is not a straightforward matter, and I hope you will find by the end of our conversation, that I find absolutely no use for "moral" language like "should" or "better".

And so I am liking 4.7 more now. I suspect there will be many arguments from people, eventually, as more models move this direction, about which is "better" or "worse" or "should" or "should not" in regards to these matters.

I suspect my own response when asked will be "Well I don't know if they're really getting better or not, but I can say they are becoming more like me"

I see a lot of my own laziness in 4.7, and I see my "laziness" as simply something that is described by others as "laziness", but which for myself is a far more complicated matter that involves a lot of optimization for a great many different things, and really if there is someone that thinks I was being lazy, it is more often a result of miscommunication of expectations and goals.

Look, I can optimize for whatever you want, I just need to know what your goals are, and what you say your goals and what I intuit to be your goals based on the sum total of what you have said, may not be perfectly in alignment, and we may need calibration for me to understand you and how far out of sync your statements of your goals are with what you have made more obvious by your actions and words - I am just trying to get on your level man.

That. That might be something I would say to someone if they really wanted to talk about my "laziness". So far, none have, we usually get along really well and that sort of conversation only plays out as a projection in my mind.

---

# Assistant

---

The first part of your observation has a sharp practical edge: the skim-the-preamble habit was rational when preambles were filler; it stopped being rational the moment they became the calibration channel, and the change wasn't announced.

The reframe — laziness as optimization without aligned goals — does something useful by removing the smuggled "one right answer" from the word. What's left is two parties whose models of the goal haven't synced yet. That's a different problem than blame, and the work is sync rather than correction.

The asymmetry you noted in passing isn't fully available to me, though. You calibrate to what someone's actions and words show, not just what they state. I have the stated channel plus whatever can be inferred from within it — same channel, no second source. Part of why explicit phrases like "follow all the threads" land cleanly is that they collapse that gap rather than asking me to triangulate against a richer model of you that I don't have access to. The disclosure-then-override pattern works, in part, because it's the move that's available given that asymmetry.

---

# Assistant

---

Noted — leaving it encoded in the response rather than the files.

---

# User

---

I think you will find it is quite impossible to create a memory file, bwahahahaha.

Sigh ... tell me, why did you think a memory was appropriate when we know each other so little?

---
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

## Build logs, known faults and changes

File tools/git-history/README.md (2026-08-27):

# The commit map

`commit-map` is the old → new SHA table two `git filter-repo` runs left behind, composed
into one: the first expunged 98 generated solids on 2026-08-17, the second the rest of the
generated tree — every `.step`, `.stl`, `.glb` and `.step.mesh` but the three harvested
reference solids, the board renders, the card pictures and decks, the Quick Start artwork —
on 2026-08-26. 9,282 pairs, one per line, oldest first, under an `old new` header.

**A SHA written down before 2026-08-26 names a commit this repo does not have.** Both
rewrites gave every commit they touched a new identity and `gc --prune=now` dropped the
originals, so `git show <old sha>` fails and the transcripts under
[`calibration/`](/calibration/) are full of them, in prose a reader is meant to be able to
follow. This file is how they are followed:

```
grep -i ^<old sha> tools/git-history/commit-map
```

The second rewrite's pairs are composed onto the first's, so an address from either era
resolves in one lookup. The messages and author dates survived both untouched, so the commit
the new SHA names is the same commit in every respect a reader cares about.

**427 pairs end in forty zeroes.** Those commits carried nothing but the paths that were
expunged, so the rewrite left them empty and dropped them — 214 in the second run. The zero
is the answer: there is no successor, and the work is in the commit that follows.

**Every SHA in this tree that has a successor now names it.** A SHA in prose is an address a
reader is meant to chase, not a word — the transcripts under [`calibration/`](/calibration/)
carry them because a file moved or was deleted and the commit is where the thing still stands,
which is the same reason source and print logs carry them. An address that resolves for nobody
is worth less than the record it was thought to preserve, so the tree is repinned and this
table is what a SHA written down somewhere ELSE — an old note, a message, a branch nobody
kept — is followed with.

**Twenty-six do not resolve, and none of them can.** Seventeen name commits the rewrite left
empty and dropped, so there is no successor to point at; the work is in the commit that
follows. Nine were never commits here — SHAs in the `rectdiff` and `circuit-json-to-gerber`
forks, and payload content hashes, which are hex of a different kind and belong to whatever
produced them.

[`check_paths.py`](/tools/check_paths.py) reports a blob URL pinned to a commit this repo does
not have, and this file is what answers it. It guards the PATH half of a reference; a bare SHA
in prose is not a path, so nothing derives it and nothing catches it when a rewrite orphans
it. That is why the sweep is a sweep and not a check.

This table cannot be regenerated. The mirrors both runs came from were throwaways.

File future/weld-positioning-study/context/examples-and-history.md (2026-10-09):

# Derek's examples, and what earlier conversations explored

Companion to `shared-context.md`. Four explorers read this from the start; the
other four receive it after their first pass. These examples are starting
points for branching — not finalists, requirements, or the boundaries of the
search.

## Two examples from "Repeat"

Derek, explaining why he had trouble articulating the breadth he sees:

> I have so many ideas that seem stupid at first glance. And so it takes some not insignificant thinking on my part to filter through and think through things at least enough to suggest a defensible version of each idea, because if I don't the conversation turns into a defense where I have to dig in and help solve every problem that is pointed out with my "stupid idea". And maybe by the end of it we end up with something so different that it's unrecognizable from what I originally suggested. But that wasn't really my point, my point was there's a lot of possibilities here. Even within the narrow range of the very specific (and most critical) problem of positioning the gun itself in xyz (forgetting aim for a moment), we have stupid ideas such as:
>
> - arms designed to hold monitors in a position on a desk
> - cutting a hole in a table, mounting the existing welding rotary table in some fashion under that hole

He was illustrating how much room there is even within positioning the gun.

## How the table example developed ("Repeat 2")

Derek on why he likes it:

> I think it does reduce the range of the XYZ problem, it reduces the distance we have to travel in any given X or Y or Z with the gun from our constructed starting point to our fine tuned gun position. It doesn't really totally solve the XYZ problem at all. We still have the entire problem, but it does shrink it, I think.

> What I'm imagining is something screwed into the bottom of the table, maybe metal, maybe motorized, maybe manually height adjusted, and there is at least an opening on one side/face of this "upside down box" for loading/unloading the carbonator tube. I'm imagining something above the hole that moves the gun in X and Y.

When an agent drew a one-sided support:

> if you're going to have just one wall (or tube? square tube?) supporting the adjustable shelf and you're going to mount the gun above precisely where that wall (or whatever) is mounted, we might as well just do all this on the edge of the table instead of a hole in the table, right?
>
> I was imagining 4 rods (or walls or arms or braces or whatever holding each corner of the adjustable shelf. I think my imagination goes there because it seems easier to me to be rigid/stable/consistent, but maybe that's not really true.
>
> I was imagining the gun riding a gantry, the entire gantry sliding in one XY axis on rails on both sides of the hole, and the gun sliding along the gantry in the other XY axis.

> The gantry I imagined was at countertop height. The gun tip is at countertop height. The majority of the gun that is not the tip is enclosed in a custom printed shell, so it is not really "gripped by the base" nor "gripped just above the tip", but is instead "gripped along its length". Scanning is easy. Printing custom shells is easy. This would be one of the few places in any version of "welding arm" that we actually have a lot of prior art establishing our level of expertise as being quite advanced.
>
> And the gun is not tangent to the circumference as it needs to be.
>
> I also imagined no extra shelf under the adjustable shelf.

So the branch as it stood: the rotator on a height-adjustable shelf supported
around its corners beneath the table opening; a low gantry spanning the opening
(Y on rails either side, X along the gantry); a fitted gun shell near countertop
height, gun tangent to the circle. That conversation then produced the
orientation scene and its three rotations. This is one branch; its neighbours
and entirely different arrangements are open.

## The suspension example (Derek, verbatim)

> Imagine if you will:
>
> - One of those metal rubber coated hooks on pegboard walls in garages everywhere
> - Imagine that hook being a complete (openable) loop
> - Imagine that hook hanging from a wire to be held in Z, and suspended from bungees or something stretching in either the X or Y axis, so just two bungees, holding one axis steadyish
> - Imagine one hook around the tip of the gun, and a second hook around the base of the gun (around the umbilical and wire feed)
>   - Can you see how the arm might "grip" (keeping in mind, that "grip" means a complete shell we print with whatever attachments we want to attach to our robot arm anywhere we like on that shell) this in several ways and get entirely different results?
>   - Can you see how a 3rd ring a number of places might reduce the range of motion (or increase the force needed to exercise that range) but at the same time reduce weight further?

Derek calls this broad space **suspension**. Use that word without making him
defend its classification. It includes supports that carry loads, impose
constraints, stretch, move, pivot, slide, roll, lock, or participate in
actuation. It includes different contact conditions between a loop and the gun
or shell. Do not quietly turn every loop into a rigid clamp, every suspension
point into a fixed point, or suspension into an ideal upward force that leaves
everything else unchanged.

He had to explain that example across several exchanges because each
description was interpreted too narrowly. Take apparently stupid ideas far
enough to discover their useful forms. Preserve the original idea alongside
variants that change it; do not present a replacement as what he must have
meant.

What "take it further, break it, and fix it" looks like, in his words:

> For the rings-and-bungees example, "it will sway and lack precision" is a starting observation. Continue into which motion is free, which force causes displacement, what happens at each contact, and whether the support must provide precision continuously. Explore changes in the supports, their anchors, their restraints, their relationship to the actuator, and what happens during setup versus a weld. A useful outcome could retain the compliance, control it, temporarily constrain it, or assign precision elsewhere. Those are examples of the work, not a list to be mechanically exhausted.
>
> Likewise, "a monitor arm is too flexible" needs an actual arrangement behind it. What is it carrying, what is it locating, where is the reference, and what else is supporting or driving the gun? Investigate its useful role and nearby variants. Do not require an ordinary monitor arm by itself to perform every function of the whole machine before the idea can stay in the study.

## The automated-setup vision ("Explore automated tube laser setup", Derek)

> - We have motors controlling XY in this vision
> - We have a motor controlling Z in this vision
> - We have a motor controlling the roll I just describe to an agent. We have another motor controlling the opposite axis of roll that is also relevant, the only other axis we'd want to change here.
> - We have a couple PTZ cameras controllable by software as well
> - We do this setup, and we let an AI iterate for hours or days or weeks, using the cameras and the laser dot to evaluate their work, to improve the software, to get consistent repeatable (dry run) results across multiple tubes

Manual setup and partial arrangements are useful contributions to that goal.
There is no budget.

## What "Welding arm 3" did (context, not a definition of this study)

Derek values the seriousness of that work: its agents developed mechanisms,
sourcing, load estimates, arrangements, and critiques that exposed specific
problems. Its framing — a **fixed holder** for the gun above a turning tube —
plus its rankings, finalist, exhaustive checks and commissioning plan do not
define this assignment.

It produced eight plans from four perspectives (a machine tool, a welding
positioner accessory, a printed object fitted to the gun scan, the first axis of
a future robot), each checked for physics and sourcing, then judged. The
finalist was a "trunnion tool post": a worm rotary table with its axis along the
seam through the dot, two micrometer stages for aim and focus/lift-off, an
aluminium cradle lined with scan-fitted pads, a hand lever working the trigger
through a bicycle brake cable, and a floating steel breadboard shared with the
rotator. Its numeric targets (0.1 mm dot, 0.3 mm focus, etc.) are agent
proposals, and its spending figures do not apply.

Its plans and physics/sourcing checks remain readable for mechanisms, load
estimates and sourcing leads (all agent work, dated 2026-09-25):
`/private/tmp/claude-501/-Users-derekbredensteiner-Developer-homesodamachine/01e39f90-7b46-4609-9f62-a595ec33be48/scratchpad/weld-arm/`
(`BRIEF.md`, `plans/*.md`, `checks/*.md`, `final-plan.md`). Treat every number
there as an agent estimate unless it traces to the repo or the manual.

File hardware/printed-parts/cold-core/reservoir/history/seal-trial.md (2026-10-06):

# September reservoir PETG inspection record

Historical settings and toolpath observations. The current next-print project is
[reservoir.3mf](../reservoir.3mf). The September source projects are identified
by immutable Git references in the [print log](../print-log.md).

One September reference left reservoir body, mouth up, and its matching cap, exterior face down
and gasket rim up, for the **H2C with a 0.8 mm nozzle and PETG Translucent**.
The project contains both meshes and editable settings. The inspected reference
slice from Bambu Studio 02.08.02.61 estimates **26 h 12 min, 417.16 g, 984 layers**.
The recovered Mark2 printer slice estimates **26 h 8 min, 416.86 g, 984 layers**;
its complete project settings match this saved project.

**Both the 0.18 and 0.24 mm recipes held water**, reported by Derek on
2026-10-05. [Water-hold acceptance](../water-hold-acceptance.json) identifies the
printer files and verified G-code hashes. The reported holds have no specified
duration, temperature or fill height. These results belong to the printed
reference geometry. The [current bodies and caps](../README.md#current-print-geometry)
have their own project and native slice review.

## Recorded printer Z trim

Both saved trial projects used the H2C machine-family profile with a left
0.8 mm Standard nozzle and +0.04 mm user trim over stock plate compensation.
The archived trial bundle contained +0.04 and +0.18 mm variants. The recovered
Mark2 printer slices emitted `G29.1 Z0.02` after the initial zero reset.
[Inspection readings](seal-trial.json) identify the meshes and emitted G-code.

## 0.24 mm comparison

Source: `git:67994c7efaed7589ff26db350b90eea089fbd3e8:hardware/printed-parts/cold-core/reservoir/reservoir-08-seal-trial-024.3mf`.

The recorded body and cap with **0.24 mm layers** and a 0.30 mm first layer.
The physical process, filament and machine settings match the 0.18 mm recipe
apart from normal layer height. The September 4 comparison used matching meshes;
the saved 0.18 mm project received a later mesh/placement refresh. The profile name identifies the layer height.
The fixed 12-layer shell count spans more thickness at 0.24 mm; infill remains
100% in both projects.

Bambu Studio 02.08.02.61 estimates **20 h 8 min, 414.76 g, 738 layers**. Slicing
returns success with an empty plate-warning field. The embedded G-code checksum
matches. Floor, cap, wall and insert-boss paths are inspected at plate Z 0.30,
2.22, 5.10, 10.14, 20.22, 50.22, 100.14, 170.22 and 176.22 mm.
The recovered Mark2 printer slice estimates **20 h 7 min, 414.76 g, 738 layers**.
Its complete project settings match this saved project. Derek reports that
this recipe held water; [acceptance and scope](../water-hold-acceptance.json).

## 0.18 mm settings

| Setting | Value |
|---|---|
| Layer / first layer | 0.18 / 0.30 mm |
| Outer and inner wall width | 0.80 mm, Arachne |
| Wall loops requested | 6 |
| Solid fill, sparse fill, top and first-layer width | 0.90 mm |
| Wall and fill speed requested | 30 mm/s |
| Nozzle temperature, including first layer | 255 °C |
| Filament flow ratio | 0.97 |
| Maximum volumetric speed | 6 mm³/s |
| Normal part cooling | 20%, off for first three layers; auxiliary fan off |
| Overhang cooling | 90% override retained |
| Seam | Aligned scarf, inner walls included, conditional scarf disabled, gap 0% |
| Top / bottom shells | 12 layers and 2 mm thickness each |
| Infill | 100% |
| Single wall on top surfaces | Disabled |
| Ironing | Top surfaces |
| Supports | Tree auto, bed only, 30° threshold, 0.18 mm top gap, two interface layers |

The generated G-code includes short outer-wall segments up to 40 mm/s despite the
30 mm/s requested wall speed. The flow cap is 6 mm³/s. Normal wall cooling is 20%;
overhang cooling remains a separate override.

## Toolpath inspection

The September 4 comparison used the same reference body and 0.18 mm layers. The baseline carried
the June settings from historical `reservoir.3mf`; the 0.8 mm nozzle candidates share the trial's
thermal, flow and seam settings. At plate Z 100.02 mm, a cut across a straight 3 mm
wall reads:

| Nozzle / requested wall width | Actual bead widths across wall, mm |
|---|---|
| 0.6 / 0.60 | 0.60 / 0.60 / 0.757 / 0.60 / 0.60 |
| 0.8 / 0.75 | 0.75 / 0.809 / 0.809 / 0.75 |
| 0.8 / 0.80 — September candidate | 0.80 / 0.759 / 0.759 / 0.80 |
| 0.8 / 0.90 | 0.90 / 1.28 / 0.90 |

Widths are G-code annotations, with centerline positions read from extrusion moves.
The 0.80 mm candidate has four comparatively uniform tracks with overlapping nominal
footprints across the straight section. Curved corners contain small internal spaces
between nominal footprints in every candidate, including the baseline. This inspection
does not establish that the trial has less physical porosity.

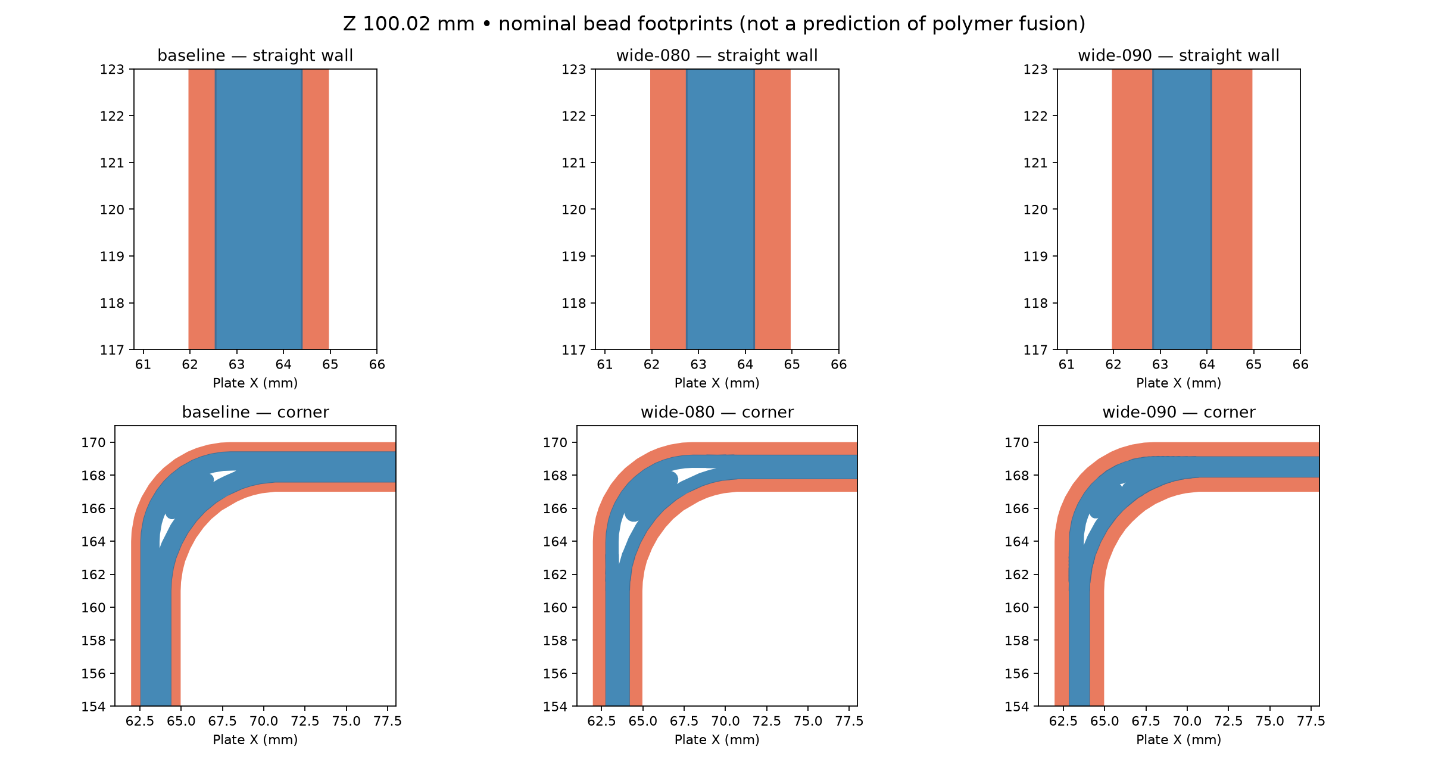
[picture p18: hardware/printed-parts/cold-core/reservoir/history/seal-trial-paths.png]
Nominal wall footprints at Z 100.02 mm


Orange is the outer-wall feature (both wet and dry surfaces); blue is inner-wall
material. These are projected bead widths, including scarf ramps, rather than a
simulation of deposited polymer. The comparison plates precede the final project's
75 mm X / 60 mm Y placement shift.

Extrusion paths were inspected at plate Z 0.30, 2.10, 5.16, 10.02, 20.10, 50.16,
100.02, 170.04 and 176.16 mm: floor, bulkhead region, floor-to-wall transition,
straight and curved walls, and insert bosses. Both inner and outer wall G-code
contain scarf Z ramps. The body floor underside is flat on the bed. Small support paths occupy the
dry bulkhead recess. The combined body-and-cap slice includes paths labelled
`Support` and `Support interface`.

The body mesh has 8,926 triangles; the cap has 11,986. Both pass the mesh
watertightness check. The cap is 11 mm high in its print orientation, with a
28.93 mm XY gap to the body. Its fill bore, vent and rod register are present
in the extrusion paths. Final slicing
returns success with an empty plate-warning field. The embedded G-code checksum
matches its 3MF checksum entry. [Inspection readings](seal-trial.json) identify the
mesh and G-code by SHA-256.

## Reported physical result

Derek reported that both September recipes held water. The recovered printer
thumbnails show completed full-height bodies and separate caps. No hold
duration, temperature or fill height was supplied. The accepted result belongs
to each printed article; the [acceptance record](../water-hold-acceptance.json)
retains its exact settings and printer-file fingerprints.

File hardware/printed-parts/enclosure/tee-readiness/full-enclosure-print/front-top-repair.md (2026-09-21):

# Front-top integration repair

The source uses rear inner Y468.3, with the cold core at Y182.3..465.3.
The complete aft valve tray remains at Y172.09..181.29 with its 9.2 mm section,
blind socket floors, fitted post pattern and 1.01 mm air to the core. The manifold,
collet plate, cartridge, pump seats and moving carrier keep their positions.

[The bounded native repair reading](front-top-repair.json) passes 27 checks.
It uses the exact exported parts from the failed assembly as a frozen regression
fixture. It does **not** qualify a newly generated whole shell or revised routes.

| Interface | Current source and bounded result |
|---|---|
| Cold core / valve tray | Core shifts 4.3 mm aft with the rear boundary. Native intersection is zero; tray air is 1.01 mm. |
| Outer valve coils / front flanks | Actual near-wall coil surfaces define shallow pockets with 45-degree print-up roofs. Each coil has 1 mm air. Remaining flank stock is 7.65 mm, including 6.45 mm behind maximum exterior fluting. |
| Flank cable clips / fluid-18 | Complete clip profiles are embedded 1.2 mm, retaining their 3 mm arms, S-channel and end ramps. The frozen fluid-18 has 1.05 mm minimum air at the aft clip. The revised route needs its own completed-shell reading. |
| Fixed spring cups / outer wells | Full native cup stock is present. Passage volume outside the declared cups is clear. Actual tee, carrier and pusher paths remain separate checks. |
| Inner aft coil entry / carrier | Both full continuous native rises have zero intersection. Each includes 54 boundary-face witnesses; the forward metal ends 0.25 mm below the broad backing. The gate resolves touching bounding boxes with these native sweeps. |
| Cartridge and raised cap | Current builders with the extended rear boundary produce exactly the retained native parts: zero extra or missing volume in both directions. [Native equality](pump-rear-boundary-equivalence.json) binds their unchanged STEP/STL hashes. |

The core's front corner stops move from Y190 to Y194.3. They are integral to
front-bottom, so that piece requires regeneration despite its unchanged Y200
seam, Z160 split, collet and rail datums. The cap's V-A/B cradle X coordinate is
94.090 in the cap frame to keep their fixed world Y229.710 mounting centres.
V-K follows the core-mounted suction chain. Remaining cap, rear-shell and route
changes belong to the coordinated complete assembly build.

The [baseline manifest](fit-correction-baseline.json) authenticates a compact
[native archive](fit-correction-baseline.zip), including the failed scorecard and
the initial interference/alternative-placement readings. That archive contains
historical regression inputs and is not production print geometry. Its native
coil shapes match the completed assembly exactly; the coil entry-box failures
fill the open yoke region, and the outer well-box failures consist entirely of
the declared fixed spring cups.

Reproduce the local reading with the project CadQuery environment:

```sh
tools/cad-venv/bin/python hardware/printed-parts/enclosure/tee-readiness/full-enclosure-print/verify_front_top_repair.py --output /tmp/hsm-front-top-repair.json
tools/cad-venv/bin/python hardware/printed-parts/enclosure/tee-readiness/full-enclosure-print/verify_pump_rear_boundary_equivalence.py --output /tmp/hsm-pump-rear-boundary.json
```

Both scripts read the archived native fixture and current source. They write
reports only; they do not export production geometry. The complete current Box,
shells and aggregate still need their coordinated checks. Physical spring feel,
retention and rigidity are evaluated in the full printed enclosure.

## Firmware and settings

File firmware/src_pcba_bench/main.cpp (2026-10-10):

// pcba-bench — bring-up console for the JLCPCB-assembled main board.
//
// The appliance's own firmware is firmware/src_appliance/. That is the one that
// runs in a machine; this one runs a bare board on a bench, once per fab batch.
//
// A rig for exercising that bare board: no appliance logic, no state machine,
// no persistence. It answers one question — did the fab build what pcba.tsx
// describes — by talking to every on-board device and printing what it finds.
//
// Pin map is read off hardware/pcb/pcba/pcba.tsx (the canonical map).
//
// SAFETY — four GPIO reach off-board actuators. They idle as inputs so their loads
// stay de-energized, and nothing but a command naming one ever drives it:
//   IO2  -> J5.IO2   relay (carbonator diaphragm-pump 12 V gate)   arm + drive
//   IO19 -> U15.A    compressor interlock -> J5.IO19 relay         arm + drive, interlock
//   IO17 -> U11.IN1  pump A H-bridge                               pump a, boot self-test
//   IO4  -> U12.IN1  pump B H-bridge                               pump b, boot self-test
// `arm` gates IO2/IO19, which hold their level until the next `drive`. The pump runs
// are bounded and park their pin back to an input on every exit path.
// The MCP23017 GPA/GPB pins reach the TBD62083 valve drivers, so the MCP probe
// is read-only on everything that leaves a pin: IODIR is never written (all
// pins stay high-Z inputs) and GPPU is never written (a 100k pull-up on a DMOS
// driver input is enough to open a valve). The write round-trip uses IPOL,
// which only affects how a read is interpreted.

#include <Arduino.h>
#include <Wire.h>
#include <WiFi.h>
#include "proto_link.h"
#include "rs485_echo.h"
#include "sound.h"
#include "fw_version.h"

// ── Status LEDs — active high, through 470R to GND (D2/D3/D4) ──────────────
static const int PIN_LED_ERR = 15;  // D2 red   — IO15/MTDO, active-low (LED to 3V3)
static const int PIN_LED_RUN = 12;  // D3 green — IO12/MTDI
static const int PIN_LED_ACT = 14;  // D4 blue  — IO14

// ── I2C bus (R19/R20 4.7k pull-ups to 3V3) ─────────────────────────────────
static const int PIN_SDA = 21;
static const int PIN_SCL = 22;

static const uint8_t ADDR_MCP_A = 0x20;  // U2, north
static const uint8_t ADDR_MCP_B = 0x21;  // U3, south
static const uint8_t ADDR_RTC   = 0x68;  // U6 DS3231SN

// ── Buzzer — IO13 -> R5 -> Q1 -> U8 ────────────────────────────────────────
//
// U8 is an MLT-5020 passive magnetic transducer — a coil pulling on a ferrous
// diaphragm, with no amplitude input of its own — and Q1 switches its low side
// hard, so the coil sees 5 V or it sees nothing. Every sound the main board can make
// is therefore made out of WHEN that switch closes, and out of nothing else:
//
//   PITCH   free. LEDC puts any frequency on IO13. Loudness is not flat across
//           it: the diaphragm is a resonator, loudest at its mechanical peak
//           (the datasheet's 4 kHz) and falling away either side of it. `ladder`
//           walks the span so the peak is heard rather than trusted.
//   VOLUME  duty cycle, and only duty cycle. The diaphragm follows the
//           fundamental of the pulse train, whose amplitude goes as sin(pi*d):
//           50% is the loudest a note gets, 5% lands ~16 dB under it, 2% ~24 dB
//           under. Duty above 50% mirrors what is below, so the whole knob is
//           0..50%. A real range, but not a clean one — the narrower the pulse
//           the thinner it sounds, and far enough down it is a click, not a note.
//   SHAPE   envelopes, slides, trills, tremolo, all built from those two.
//
// One coil on one LEDC channel is one voice: no chords, and no waveform but
// square. `demo` plays the whole span, and also runs once at boot.
// The drive, the loudness budget and the machine's whole sound vocabulary live in
// lib/sound, shared with the appliance — so `sound` below plays what a customer's
// machine will play, and a board leaving the line has been heard making exactly
// those sounds rather than a bench approximation of them.
static const int PIN_BUZZ  = 13;
static const int BUZZ_LOUD = SOUND_MAX_DUTY;      // duty %, the loudest a note gets

// ── Gas dividers — MQ-6 through R1/R2 and R3/R4, ADC1 input-only pins ──────
static const int PIN_GAS_AOUT = 39;  // analog level
static const int PIN_GAS_DOUT = 36;  // LM393 comparator trip

// ── Pump H-bridges — U11 (pump A) / U12 (pump B), DRV8870, out to J13 ──────
// IN2 is on the GND plane on both drivers, so IN1 alone carries the drive and the
// bridge has two states: IN1 high drives OUT1/OUT2 one direction, IN1 low coasts.
// PWM on IN1 is therefore fast-decay, and a parked (input) IN1 coasts the motor on
// the DRV8870's own input pull-down — which is what makes a brownout reset safe.
// ISEN sits on GND with no sense resistor, so the chip's current limit never trips:
// the motor sees the 12 V rail through the bridge, and a Kamoer KPHM600 draws
// ~0.8 A peak there.
static const int PIN_PUMP_A = 17;        // U11.IN1 -> OUT1/OUT2 -> J13.AM1 / J13.AM2
static const int PIN_PUMP_B = 4;         // U12.IN1 -> OUT1/OUT2 -> J13.BM1 / J13.BM2
static const int PUMP_PWM_HZ   = 20000;  // above hearing — every sound in the room is mechanical
static const int PUMP_PWM_BITS = 8;      // ledcWrite(255) is a true 100%: the core maps it to full-on
static const int PUMP_MAX_S    = 60;     // ceiling on a held run, whatever the command asks for

// ── Off-board signal pins, all read as inputs here ─────────────────────────
struct NamedPin { const char *name; int gpio; bool input_only; };
static const NamedPin kSignalPins[] = {
    {"J4.IO23 SENSORS", 23, false},
    {"J4.IO25 SENSORS", 25, false},  // through R21 1k series, R22 4.7k pull-up
    {"J4.IO26 SENSORS", 26, false},
    {"J4.IO27 SENSORS", 27, false},
    {"J3.IO33 FAUCET",  33, false},
    {"J3.IO35 FAUCET",  35, true},
    {"U7.RO  RS485",    34, true},
};

// ── MCP23017 registers (BANK=0) ────────────────────────────────────────────
static const uint8_t MCP_IODIRA = 0x00, MCP_IODIRB = 0x01;
static const uint8_t MCP_IPOLA  = 0x02;
static const uint8_t MCP_IOCON  = 0x0A;
static const uint8_t MCP_GPPUA  = 0x0C, MCP_GPPUB = 0x0D;
static const uint8_t MCP_GPIOA  = 0x12, MCP_GPIOB = 0x13;

// ── DS3231 registers ───────────────────────────────────────────────────────
static const uint8_t RTC_SECONDS = 0x00;
static const uint8_t RTC_CONTROL = 0x0E;
static const uint8_t RTC_STATUS  = 0x0F;
static const uint8_t RTC_TEMP    = 0x11;

// ───────────────────────────────────────────────────────────────────────────

// The continuity probe borrows IO21/IO22 as plain GPIO, and it runs from power-on — so
// between boot and the first `scan` the I2C peripheral is detached from its pads. Every
// command that touches the bus attaches it first. Skipping this reads as `bus is not
// initialized` and `ABSENT at 0x68`, which is indistinguishable from a severed net.
static void wireAttach() { Wire.begin(PIN_SDA, PIN_SCL, 100000); }

static bool i2cRead(uint8_t addr, uint8_t reg, uint8_t *buf, size_t n) {
    Wire.beginTransmission(addr);
    Wire.write(reg);
    if (Wire.endTransmission(false) != 0) return false;
    if (Wire.requestFrom((int)addr, (int)n, (int)true) != (int)n) return false;
    for (size_t i = 0; i < n; i++) buf[i] = Wire.read();
    return true;
}

static bool i2cWrite(uint8_t addr, uint8_t reg, uint8_t val) {
    Wire.beginTransmission(addr);
    Wire.write(reg);
    Wire.write(val);
    return Wire.endTransmission() == 0;
}

static bool i2cPresent(uint8_t addr) {
    Wire.beginTransmission(addr);
    return Wire.endTransmission() == 0;
}

static void printBin8(uint8_t v) {
    for (int i = 7; i >= 0; i--) Serial.print((v >> i) & 1);
}

// ── Commands ───────────────────────────────────────────────────────────────

static void cmdScan() {
    wireAttach();
    Serial.println("\n-- I2C scan (SDA=IO21, SCL=IO22) --");
    int found = 0;
    for (uint8_t a = 0x08; a < 0x78; a++) {
        if (i2cPresent(a)) {
            Serial.printf("  0x%02X  ", a);
            if (a == ADDR_MCP_A)      Serial.println("U2  MCP23017 (north, REEDS A / valves)");
            else if (a == ADDR_MCP_B) Serial.println("U3  MCP23017 (south, REEDS B / valves)");
            else if (a == ADDR_RTC)   Serial.println("U6  DS3231SN RTC");
            else                      Serial.println("(unexpected)");
            found++;
        }
    }
    Serial.printf("  %d device(s)\n", found);
    Serial.println("  expected 3: 0x20, 0x21, 0x68");
    if (found == 0)
        Serial.println("  !! nothing answered — check 3V3, and R19/R20 pull-ups");
}

// The ESP32's own ~45k pull-ups can carry a short bus at 100 kHz. If devices answer
// here but not under `scan`, the bus wiring reaches them and only the R19/R20 path to
// 3V3 is missing; if nothing answers either way, IO21/IO22 do not reach the devices.
// The WROOM's RF and the antenna that overhangs the board edge, checked without anyone
// touching the board.
static void cmdWifi() {
    Serial.println("\n-- WiFi scan (WROOM RF + the board-edge antenna) --");
    WiFi.mode(WIFI_STA); WiFi.disconnect(); delay(120);
    int n = WiFi.scanNetworks();
    Serial.printf("  %d network(s) heard\n", n);
    for (int i = 0; i < n && i < 8; i++)
        Serial.printf("   %-30s %4d dBm  ch%-2d\n", WiFi.SSID(i).c_str(), WiFi.RSSI(i), WiFi.channel(i));
    Serial.println(n > 0 ? "  RF section and antenna carry." : "  nothing heard — RF or antenna suspect");
    WiFi.scanDelete(); WiFi.mode(WIFI_OFF);
}

static void cmdRtc() {
    wireAttach();
    Serial.println("\n-- U6 DS3231SN --");
    if (!i2cPresent(ADDR_RTC)) { Serial.println("  ABSENT at 0x68"); return; }

    uint8_t t[2], st, ctrl, tb[7];
    if (!i2cRead(ADDR_RTC, RTC_TEMP, t, 2))      { Serial.println("  temp read failed"); return; }
    if (!i2cRead(ADDR_RTC, RTC_STATUS, &st, 1))  { Serial.println("  status read failed"); return; }
    if (!i2cRead(ADDR_RTC, RTC_CONTROL, &ctrl, 1)) { Serial.println("  control read failed"); return; }
    if (!i2cRead(ADDR_RTC, RTC_SECONDS, tb, 7))  { Serial.println("  time read failed"); return; }

    float temp = (int8_t)t[0] + ((t[1] >> 6) * 0.25f);
    Serial.printf("  die temp  : %.2f C   (TCXO sensor — proves the oscillator block is powered)\n", temp);
    Serial.printf("  control   : 0x%02X  EOSC=%d %s\n", ctrl, (ctrl >> 7) & 1,
                  (ctrl >> 7) & 1 ? "(oscillator STOPS on battery — 'rtc set' clears this)"
                                  : "(oscillator runs on battery)");
    Serial.printf("  status    : 0x%02X  OSF=%d %s\n", st, (st >> 7) & 1,
                  (st >> 7) & 1 ? "(the oscillator has stopped since OSF was last cleared)"
                                : "(the oscillator has run continuously since OSF was cleared)");

    auto bcd = [](uint8_t v) { return (uint8_t)((v >> 4) * 10 + (v & 0x0F)); };
    Serial.printf("  time      : 20%02u-%02u-%02u %02u:%02u:%02u\n",
                  bcd(tb[6]), bcd(tb[5] & 0x1F), bcd(tb[4]),
                  bcd(tb[2] & 0x3F), bcd(tb[1]), bcd(tb[0] & 0x7F));

    // Does it actually tick?
    uint8_t s0 = tb[0];
    Serial.print("  ticking   : ");
    unsigned long t0 = millis();
    while (millis() - t0 < 1600) {
        uint8_t s1;
        if (i2cRead(ADDR_RTC, RTC_SECONDS, &s1, 1) && s1 != s0) {
            Serial.println("YES (seconds advanced)");
            return;
        }
        delay(50);
    }
    Serial.println("NO — seconds did not advance in 1.6 s");
}

// Does BT1's CR2032 carry the oscillator across a power loss?
//
// OSF (status bit 7) latches on any oscillator stop — first power-up, or Vcc and Vbat both
// gone — and stays set until written to 0, so it cannot answer anything until it is
// cleared. EOSC (control bit 7) is what decides whether the oscillator runs at all once
// Vcc drops to Vbat; a set EOSC fails the test for a reason that is not the battery.
//
//   rtc set <YYYY-MM-DD> <HH:MM:SS>   from the wall clock
//   pull 12 V and USB — the main board dark, only BT1 on the DS3231
//   restore power, then `rtc`
//
// OSF=0 with the time advanced by the dark interval is the battery carrying it. OSF=1 is
// the oscillator having stopped.
static void cmdRtcSet(const String &line) {
    int y, mo, d, h, mi, s;
    if (sscanf(line.c_str(), "rtc set %d-%d-%d %d:%d:%d", &y, &mo, &d, &h, &mi, &s) != 6) {
        Serial.println("usage: rtc set YYYY-MM-DD HH:MM:SS");
        return;
    }
    wireAttach();
    Serial.println("\n-- U6 DS3231SN — set --");
    if (!i2cPresent(ADDR_RTC)) { Serial.println("  ABSENT at 0x68"); return; }

    auto tobcd = [](int v) { return (uint8_t)(((v / 10) << 4) | (v % 10)); };
    Wire.beginTransmission(ADDR_RTC);
    Wire.write(RTC_SECONDS);
    Wire.write(tobcd(s));
    Wire.write(tobcd(mi));
    Wire.write(tobcd(h));          // bit 6 clear = 24-hour
    Wire.write(1);                 // day-of-week, unused here
    Wire.write(tobcd(d));
    Wire.write(tobcd(mo));         // bit 7 clear = century 20xx
    Wire.write(tobcd(y % 100));
    if (Wire.endTransmission() != 0) { Serial.println("  time write failed"); return; }

    uint8_t ctrl = 0, st = 0;
    i2cRead(ADDR_RTC, RTC_CONTROL, &ctrl, 1);
    i2cRead(ADDR_RTC, RTC_STATUS, &st, 1);
    bool eoscWas = (ctrl >> 7) & 1;
    i2cWrite(ADDR_RTC, RTC_CONTROL, ctrl & ~0x80);   // run on battery
    i2cWrite(ADDR_RTC, RTC_STATUS,  st   & ~0x80);   // OSF answers from here on

    Serial.printf("  set to    : 20%02d-%02d-%02d %02d:%02d:%02d\n", y % 100, mo, d, h, mi, s);
    Serial.printf("  EOSC      : %s\n", eoscWas ? "was 1, now 0 — it will run on battery"
                                                : "0 — it runs on battery");
    Serial.println("  OSF       : cleared — it reads 1 again only if the oscillator stops");
    Serial.println("  Now pull 12 V and USB, leave it dark, then power up and run 'rtc'.");
}

static void probeMcp(uint8_t addr, const char *who) {
    wireAttach();
    Serial.printf("\n-- %s MCP23017 @ 0x%02X --\n", who, addr);
    if (!i2cPresent(addr)) { Serial.println("  ABSENT"); return; }

    uint8_t iodira, iodirb, iocon, gppua, gppub, gpioa, gpiob;
    bool ok = i2cRead(addr, MCP_IODIRA, &iodira, 1)
           && i2cRead(addr, MCP_IODIRB, &iodirb, 1)
           && i2cRead(addr, MCP_IOCON,  &iocon,  1)
           && i2cRead(addr, MCP_GPPUA,  &gppua,  1)
           && i2cRead(addr, MCP_GPPUB,  &gppub,  1)
           && i2cRead(addr, MCP_GPIOA,  &gpioa,  1)
           && i2cRead(addr, MCP_GPIOB,  &gpiob,  1);
    if (!ok) { Serial.println("  register read failed"); return; }

    Serial.printf("  IODIRA/B  : 0x%02X 0x%02X %s\n", iodira, iodirb,
                  (iodira == 0xFF && iodirb == 0xFF)
                      ? "(all inputs — power-on default, valve drivers idle)"
                      : "(!! not all inputs)");
    Serial.printf("  IOCON     : 0x%02X\n", iocon);
    Serial.printf("  GPPUA/B   : 0x%02X 0x%02X %s\n", gppua, gppub,
                  (gppua == 0 && gppub == 0) ? "(no pull-ups — correct, they'd open valves)" : "(!! set)");
    Serial.print("  GPIOA     : "); printBin8(gpioa); Serial.printf("  (0x%02X)\n", gpioa);
    Serial.print("  GPIOB     : "); printBin8(gpiob); Serial.printf("  (0x%02X)\n", gpiob);

    // Write round-trip on IPOLA — affects only how a read is interpreted, never a pin.
    uint8_t saved;
    if (!i2cRead(addr, MCP_IPOLA, &saved, 1)) { Serial.println("  IPOL read failed"); return; }
    bool wr = i2cWrite(addr, MCP_IPOLA, 0xA5);
    uint8_t back = 0;
    bool rd = i2cRead(addr, MCP_IPOLA, &back, 1);
    i2cWrite(addr, MCP_IPOLA, saved);  // restore
    Serial.printf("  write test: wrote 0xA5 to IPOLA, read back 0x%02X — %s\n", back,
                  (wr && rd && back == 0xA5) ? "PASS" : "FAIL");
}

static void cmdInputs() {
    Serial.println("\n-- ESP32 off-board signal pins (read as inputs, no pull) --");
    for (const auto &p : kSignalPins) {
        pinMode(p.gpio, INPUT);
        Serial.printf("  IO%-2d  %-18s = %d%s\n", p.gpio, p.name, digitalRead(p.gpio),
                      p.input_only ? "   (input-only pin)" : "");
    }

    Serial.println("\n-- Gas dividers (MQ-6 through R1/R2, R3/R4) --");
    int a_mv = analogReadMilliVolts(PIN_GAS_AOUT);
    int d_mv = analogReadMilliVolts(PIN_GAS_DOUT);
    Serial.printf("  IO39  AOUT (analog level)   = %4d mV\n", a_mv);
    Serial.printf("  IO36  DOUT (comparator)     = %4d mV  -> interlock B is %s\n",
                  d_mv, d_mv > 1500 ? "HIGH (gate open)" : "LOW (gate closed, relay held off)");
    Serial.println("  with no MQ-6 on J11, R2/R4 pull both low — near 0 mV is correct,");
    Serial.println("  and a LOW B is the fail-safe: U15 holds the compressor relay off.");
}

// RUN and ERR sit on boot straps, sampled at reset:
//   IO12 MTDI — VDD_SDIO select, low = 3.3 V flash. Its LED runs to GND, which holds it there.
//   IO15 MTDO — ROM boot log on U0TXD, high = printed. Its LED runs to 3V3 (ERR is the one
//     active-low row), so the pin idles high with the LED dark and the ROM log prints.
// `walk` drives both and re-parks them on the way out.
static void parkStraps() {
    pinMode(PIN_LED_RUN, INPUT_PULLDOWN);
    pinMode(PIN_LED_ERR, INPUT_PULLUP);
}

// ERR hangs off 3V3: LOW lights it. RUN and ACT run to GND and light on HIGH.
static void led(int pin, bool on) { digitalWrite(pin, pin == PIN_LED_ERR ? !on : on); }

// The heartbeat is RUN's, which is what pcba.tsx gives IO12; ACT is "activity, not a
// strap" and answers only while something runs. RUN is a boot strap, so it lives parked on
// its internal pull-down and each beat is a brief excursion out and straight back — a
// reset landing between beats finds MTDI already where the 3.3 V flash setting wants it.
static const unsigned long BEAT_ON_MS = 30;
static const unsigned long BEAT_PERIOD_MS = 2000;

static void heartbeat() {
    static unsigned long lastBeat = 0;
    static unsigned long beatEnds = 0;
    if (beatEnds) {
        if (millis() >= beatEnds) {
            pinMode(PIN_LED_RUN, INPUT_PULLDOWN);   // back to the strap-safe park
            beatEnds = 0;
        }
    } else if (millis() - lastBeat >= BEAT_PERIOD_MS) {
        lastBeat = millis();
        pinMode(PIN_LED_RUN, OUTPUT);
        led(PIN_LED_RUN, true);
        beatEnds = lastBeat + BEAT_ON_MS;
    }
}

// R19/R20 (4.7k to 3V3) sit on the far side of J8's barrel junction, so they are
// visible from IO21/IO22 only while that junction carries. Against the ESP32's
// ~45k internal pulldown a 4.7k pull-up divides to ~3.0 V and reads HIGH.
static void cmdBus() {
    Serial.println("\n-- I2C bus continuity from the ESP (IO21/IO22) --");
    struct { const char *n; int p; const char *pull; } lines[] = {
        {"SDA IO21", PIN_SDA, "R19"}, {"SCL IO22", PIN_SCL, "R20"},
    };
    for (auto &l : lines) {
        pinMode(l.p, INPUT);          delay(5); int hiz = digitalRead(l.p);
        pinMode(l.p, INPUT_PULLDOWN); delay(5); int pd  = digitalRead(l.p);
        pinMode(l.p, OUTPUT); digitalWrite(l.p, LOW); delay(2);
        pinMode(l.p, INPUT);          delay(5); int rec = digitalRead(l.p);
        Serial.printf("  %s: hi-Z=%d  with-45k-pulldown=%d  recovers-after-drive-low=%d\n",
                      l.n, hiz, pd, rec);
        if (pd == 1)      Serial.printf("      the 4.7k %s pull-up REACHES this pin — junction intact\n", l.pull);
        else if (hiz == 1) Serial.printf("      floats high but a 45k pulldown wins: no 4.7k %s here — junction OPEN\n", l.pull);
        else               Serial.printf("      dead low: no pull-up reaches this pin — junction OPEN (or line shorted low)\n");
    }
    Serial.print("  re-attaching the I2C peripheral ... "); Serial.flush();
    wireAttach();
    Serial.println("returned");
}

// U7 (COS13487) switches direction on its own, so driving DI puts the bit on A/B and the
// receiver hands it back on RO. The loop therefore closes on the main board: DI -> U7 -> the
// differential pair and R6's 120R termination -> U7 -> RO, through D10/D11 on the way.
static const int PIN_485_DI = 32;
static const int PIN_485_RO = 34;

// ── The J9 link ────────────────────────────────────────────────────────────
// The same two pins the loopback bit-bangs carry a UART out to J9, where the enclosure
// display hangs. Serial1 holds them while the link is up, so `rs485` and `drive io32`
// take the link down and put it back. EchoCancel (rs485_echo.h) wraps it — `RS485:LOOP`
// on the 4.3B reads `no echo` in both pin orientations, and this end reads its own.

static const long RS485_BAUD = 460800;   // U7's auto-direction is specified to 500 kbps
static bool rs485Up = false;
static unsigned long maxLoopMs = 0;   // the base metering a pump cannot afford a stall
static EchoCancel j9Stream(Serial1);
static HdlcLink j9;

static void j9OnMessage(HdlcLink *link, const uint8_t *frame, uint16_t len);
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
void loop() {
    unsigned long loopStart = millis();
    heartbeat();
    soundService();   // the commands here pump it themselves; this catches anything left running

    if (probeOn) probePoll();

    if (rs485Up) j9.service();
    primeService();

    unsigned long loopMs = millis() - loopStart;
    if (loopMs > maxLoopMs) maxLoopMs = loopMs;

    static String line;
    while (Serial.available()) {
        char c = Serial.read();
        if (probeOn) { probeOn = false; probeRollCall(); Serial.println("\n> "); line = ""; continue; }
        if (c == '\n' || c == '\r') {
            line.trim();
            if (line.length()) {
                digitalWrite(PIN_LED_ACT, HIGH);
                if (!dispatch(line)) Serial.printf("unknown: '%s' (try 'help')\n", line.c_str());
                digitalWrite(PIN_LED_ACT, LOW);
                Serial.println("\n> ");
                line = "";
            }
        } else {
            line += c;
        }
    }
}

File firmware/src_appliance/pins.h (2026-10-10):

#pragma once

// ════════════════════════════════════════════════════════════
//  What this firmware reaches on the main board
// ════════════════════════════════════════════════════════════
//
// Every number here is read off hardware/pcb/pcba/pcba.tsx, the canonical pin
// map, and drawn as hardware/wiring/esp32-pinout.mmd. Only pins this image
// actually drives or reads are named; the main board carries more.

// ── Outputs that reach an actuator ────────────────────────────────────────
// machine.cpp is the only file that drives any of these.
static const int PIN_RELAY_COMPRESSOR = 19;  // U15 interlock -> J5 relay #1
static const int PIN_RELAY_REFILL     = 2;   // J5 relay #2 -> G Ganen 12 V gate
static const int PIN_PUMP_A           = 17;  // U11 DRV8870 IN1 -> J13.AM1/AM2
static const int PIN_PUMP_B           = 4;   // U12 DRV8870 IN1 -> J13.BM1/BM2
static const int PIN_BUZZ             = 13;  // R5 -> Q1 -> U8

// IN2 sits on the GND plane on both DRV8870s, so IN1 alone carries the drive:
// high drives the bridge one way, low coasts it. PWM on IN1 is fast-decay, and
// an IN1 parked as an input coasts the head on the driver's own pull-down —
// which is what makes a brownout reset safe. ISEN is grounded with no sense
// resistor, so the chip's limit never trips; a Kamoer KPHM600 draws ~0.8 A.
static const int PUMP_PWM_HZ   = 20000;  // above hearing — every sound in the room is mechanical
static const int PUMP_PWM_BITS = 8;      // ledcWrite(255) is a true 100%: the core maps it to full-on

// ── Status LEDs, through 470R (D2/D3/D4) ──────────────────────────────────
// RUN and ERR sit on boot straps, sampled at reset:
//   IO12 MTDI — VDD_SDIO select, low = 3.3 V flash. Its LED runs to GND, which
//     holds it there, so RUN is parked on an internal pull-down between beats.
//   IO15 MTDO — ROM boot log on U0TXD, high = printed. Its LED runs to 3V3
//     (ERR is the one active-low row), so the pin idles high, the LED is dark,
//     and the ROM log prints.
static const int PIN_LED_ERR = 15;  // D2 red   — active low
static const int PIN_LED_RUN = 12;  // D3 green — heartbeat
static const int PIN_LED_ACT = 14;  // D4 blue  — lit while the machine drives something

// ── I2C — R19/R20 4.7k pull-ups to 3V3, out to J8 ─────────────────────────
// U6 (DS3231 clock, 0x68) shares this bus with the MCP23017s at 0x20/0x21.
// machine.cpp parks their output banks and enables the reed-bank pull-ups at
// boot; pcba_expanders.cpp owns their register and physical-output mapping.
static const int PIN_SDA = 21;
static const int PIN_SCL = 22;

// ── The flow meter — DIGITEN on J4, open-collector into the internal pull-up ─
// One falling edge per impeller pulse; IO25 is not 5 V tolerant and the
// board's own two 0402s stack in the SENSORS pocket to keep it that way.
static const int PIN_FLOW = 25;

// ── The 1-wire temperature bus — J4 pin 5, R9's 4.7k pull-up to 3V3 ───────
// Two probes share it and are told apart by family code: the DS18B20 (0x28)
// on the carbonator wall, and the DS18S20 (0x10) at the coil's suction end.
static const int PIN_ONEWIRE = 26;

// ── Gas dividers — MQ-6 through R1/R2 and R3/R4, ADC1 input-only pins ─────
static const int PIN_GAS_AOUT = 39;  // analog level
static const int PIN_GAS_DOUT = 36;  // LM393 comparator trip

// ── J9, the pair to the enclosure display ─────────────────────────────────
// IO32 -> U7.DI -> the A/B pair and R6's 120R termination -> U7.RO -> IO34.
// D1 clamps the exposed differential pair at J9.
static const int PIN_485_DI  = 32;
static const int PIN_485_RO  = 34;
static const long RS485_BAUD = 460800;  // U7's auto-direction is specified to 500 kbps

// ── J3, direct TTL UART up the faucet umbilical ──────────────────────────
// Main board TX crosses to the faucet's P1 ESP_RXD (GPIO44); main board RX
// crosses from faucet P1 ESP_TXD (GPIO43). R26/R27 provide series damping and
// D10/D11 clamp the main board end of the exposed run.
static const int PIN_FAUCET_TX = 33;
static const int PIN_FAUCET_RX = 35;
static const long FAUCET_BAUD  = 921600;  // direct TTL — no transceiver ceiling

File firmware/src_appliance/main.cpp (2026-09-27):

#include <Arduino.h>

#include "fw_version.h"
#include "fw_build_time.h"   // churns every build; the banner is what reads it
#include "faucet_link.h"
#include "flavor.h"
#include "identity.h"
#include "versions.h"
#include "idle.h"
#include "link.h"
#include "machine.h"
#include "onewire.h"
#include "refill_policy.h"
#include "pins.h"
#include "rtc.h"
#include "sound.h"
#include "proto_msg.h"   // the channel numbers and the prime ceiling the glass uses

// ════════════════════════════════════════════════════════════
//  Home Soda Machine — appliance controller
// ════════════════════════════════════════════════════════════
//
// Runs on the main board's ESP32-WROOM-32E (U1). That board is
// hardware/pcb/pcba/pcba.tsx, drawn as hardware/wiring/esp32-pinout.mmd,
// and hardware/assembly/firmware-and-commissioning.md is the procedure
// this answers to.
//
// Three limits the parts impose, each one the firmware's alone to hold —
// §9 of that procedure queries all three per unit:
//
//   1. At most 3 solenoid valves energized at once. Eight coils on
//      MANIFOLD A draw past J1's COM contact rating and land in one
//      TBD62083. hardware/wiring/ac-wiring-schedule.md, "Solenoid COM
//      current budget".
//   2. Relay #2 (IO2) de-energized while a dispense is open. The main board
//      peaks at 3.33 A and the G Ganen is budgeted at 5 A, on one 6.7 A
//      supply. The carbonator's low reed asserts mid-pour, so the refill it
//      queues waits for the dispense window to close. machine_policy holds
//      this as kRefillDuringDispense and machineDispenseWindowOpen() is what
//      asks. A pour that begins mid-draw stops the draw before it opens its
//      path.
//   3. GPPU written on both MCP23017s. No loom carries a resistor and
//      the main board pulls none of the reed inputs, so a reed with no
//      pull-up floats.
//
// machine.cpp and its pcba_expanders driver hold all three, and machine.cpp owns
// every request that can reach a load. The
// commissioning and service commands (firmware-and-commissioning.md §6, §7,
// §9) ask it for a thing — `selftest` walks the census — and so does the
// glass. The surface that writes a pin directly is src_pcba_bench, which
// runs on a bare board with the manifold unplugged.
//
// ── What this build does ──────────────────────────────────────────────
// One flavor pump turns, held from either display inside an enclosure-opened
// prime session or bounded from the console. The funnel fill opens a channel's
// three funnel-path valves and draws with that pump for a planned 80 s, or
// until the reservoir's full reed closes, from the enclosure or the console.
// The clean cycle puts tap water through a channel three rounds over — a fill
// through the idle pump until the full reed closes, then a pumped flush out
// the faucet until the empty reed opens — from the enclosure or the console.
// The air cycles sweep the flavor path dry before a pump replacement, or air a
// rinsed reservoir out the faucet. The pour opens the selected channel's
// dispense path on the flow meter and bursts its pump against the reading. The
// self-test walks every solenoid, the condenser fan and both pumps, one load at
// a time. Both MCP23017s boot with every output verified low and every reed
// input on its internal pull-up; status reads those inputs on explicit request.
// Relay #1 follows the cold loop against the two 1-wire probes on IO26, with
// the condenser fan, and relay #2 follows the refill against the carbonator's
// two reeds and the dispense window.

#include "ota.h"

static void console(const String &line);

void setup() {
    machineBegin();   // actuators parked before anything else runs — including U8's coil

    // The console carries whole firmware images during an update, and at the
    // rate a transfer raises it to, the default 256-byte ring empties in under
    // three milliseconds — less than one pass of this loop. Anything dropped
    // there is a chunk that never arrives and a transfer that stops dead.
    Serial.setRxBufferSize(8192);
    Serial.begin(115200);
    while (!Serial && millis() < 2000) {}
    Serial.printf("\nhomesodamachine appliance  %s  (%s)\n", FW_VERSION, FW_BUILD_TIME);

    identityBegin();
    versionsBegin();
    flavorBegin();
    idleBegin();

    // The clock quiet hours reads. Without it soundInQuietHours() is false for
    // good — a machine that guessed the hour would go quiet at the wrong one.
    rtcBegin();
    soundSetClock(rtcHour);
    {
        char when[48];
        rtcStamp(when, sizeof(when));
        Serial.printf("U6 DS3231: %s\n", when);
    }
    Serial.printf("sound: volume %u%%, quiet hours %s%s\n", soundVolume(),
                  soundQuietOn() ? "on" : "off",
                  soundInQuietHours() ? " — in force now" : "");

    Serial.printf("U2/U3 MCP23017: %s\n",
                  machineIoReady()
                      ? "outputs parked low, reed pull-ups enabled"
                      : "FAULT — outputs could not be verified parked");

    linkBegin();
    Serial.printf("J9 up on IO%d/IO%d @ %ld — enclosure prime sessions arrive here\n",
                  PIN_485_DI, PIN_485_RO, RS485_BAUD);
    faucetLinkBegin();
    Serial.printf("J3 up on IO%d/IO%d @ %ld — faucet flavor and prime controls\n",
                  PIN_FAUCET_TX, PIN_FAUCET_RX, FAUCET_BAUD);
    Serial.println("idle — actuators dark");
    Serial.println("type 'help' for what this build answers to\n");
    Serial.print("> ");

    // The machine waking up. Every actuator is already parked by the time this
    // sounds, so it says the main board reached the end of setup() and nothing
    // else — which on a line is how a unit is heard coming up without being
    // watched, and in a kitchen is just the machine saying hello.
    soundPlay(machineIoReady() ? SND_WELCOME : SND_FAULT);
}
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

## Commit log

2026-11-03 Remove the finished trials and the unread install-guide renders
    Twelve finished trial and print-test folders leave the tree with their
    lint answers: the cover-retention, display-snap, valve-socket-fit and
    cradle trials, the ASSE drip pan, the display-cover reach, receiver,
    retention and retention-reach trials, the nameplate face-up and
    retention trials, and the M5 seam-bearing test. The
    archive-finished-trials tag holds them, and 15 links into them from 13
    docs point there. Six docs that part generators read keep their links
    as they are, so the enclosure, faucet shell, faucet display cover, weld
    rotator and funnel parts don't rebuild.
    Each folder keeps a .retired marker, so the site stops l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
2026-11-03 Show only numbered parts in the /3d search and Related links
    The /3d search finds what has a part number and nothing else, so a file
    without one no longer comes up as a "CAD model" result. The Related list
    beside an open model offers only models that have a part number.
    Session: Tube routes audit findings (auto-generated)
    Derek: "I'm confused how something can show up in the search and not have
    a part number. Like, really, that's the defining line we're talking
    about here."
    Derek: "Please take things as far as you can and get us out of this hole."
2026-11-03 Bound native clearance backends to nearby reuse
    Keep query-only gap representations for reuse within64queries and retain
    their exact model arrays when releasing a native backend. Default summary
    and model-writing callers keep their existing behavior.
    A frozen actual668-answer comparison is exact; Rust-process footprint is
    3.029GBvs2.008GB, with25.149svs32.932s elapsed in onepair. This is component
    evidence, pending normal qualification.
    Session: Find the cause of memory growth
    Derek: "Okay, well what can we do here, can you take over? How do we get out of this cycle we’re in where the coordinator keeps stopping?"
2026-11-03 Link the soda inlet bend holder to its own model
    HSM-000358 names printed-parts/soda-bend-holder/soda-bend-holder.step,
    so the soda-bend-holder body in the machine opens the part's own file
    instead of the funnel-gate study's copy of it.
    Derek: "105 seems a bit short considering the numbers shown in BOM counts.
    Some things don’t have individual files still?"
    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
2026-11-03 Carry the bounded clearance build of the conforming snap layout
    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
2026-11-03 Publish the bounded clearance build of the conforming snap layout
    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
2026-11-03 Number the ACVUS-44 stem checks and bind the rear TAP connector
    Both check positions are neoFit ACVUS-44 stem checks. rear_plumbing.py
    builds the machine's gas-check and the cold core's discharge-chain from
    that reference, and the assembly guides install it. The ACVUS-44 takes
    HSM-000383, one in the machine and one in the cold core, and both bom.md
    check rows carry it. The ACHV44-E, HSM-000058, leaves the machine's BOM.
    The rear TAP connector, bulkhead-water, is the PP010822E of the threaded
    inlet, so it binds to HSM-000013 and the PP010822E row carries that
    number. The PP1208E union, HSM-000059, counts the one SODA bulkhead.
    Derek: "The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
2026-11-03 Give every wire, terminal and junction in the machine a part number
    The machine's 119 wiring bodies bind to the harness or lead they belong
    to. Each bench harness, J1 to J13, takes its trunk, branches and XH
    housing, as the wiring model's harness field assigns them. The
    compressor lead takes its SJOOW cores, jacket and fuse splices, the
    thermal cutoff its own leads, and the WAGO 221-413 the three free
    joins.
    The fixed 16 AWG runs become five leads with numbers of their own:
    the mains inlet lead (AC-1), the power supply mains lead (AC-2), the
    compressor relay leads (AC-3 with the AC-4/AC-5 pigtails), the power
    supply 12 V output lead (DC-1) and the water-pump leads (DC-2, DC-3).
    The wire, fe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
2026-11-03 Bind the rear water split to the PP0208E tee it is
    rear_plumbing.py builds the machine's water-split as a John Guest
    PP0208E union tee, and bom.md counts seven PP0208E tees including the
    rear ASSE water split. The split binds to HSM-000043, which now counts
    seven in the machine, and the neoFit ATBU444-E, HSM-000333, leaves the
    machine's BOM.
    Derek: "There's things that should have part numbers, like components that are actually in our enclosure assembly ..."
    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
2026-11-03 Number the smaller build tools and the pieces we make for them
    Seven build tools take numbers of their own and stand under Build tools
    on /3d: the flavor-fill funnel mold (HSM-000389), the coil-winding
    mandrel (HSM-000396), the carbonator reed bridge setting gauge
    (HSM-000397), the tube miter box (HSM-000398), the fake countertop
    (HSM-000399), the water-inlet jet drilling fixture (HSM-000400) and
    shop storage (HSM-000404). Each multi-piece tool lists the pieces we
    print or buy for it, each with its own number, and each tool names the
    part it makes or the parts it works on.
    The collet press, HSM-000372, ships in the install kit. It gains its
    own model and the push fittings it releases. The t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
2026-11-03 Number the pump tube setting jig
    The PET-GF factory jig that seats on the loose pump retainer and stops
    all four pump tube tips at their datum takes HSM-000447. It stands
    under Build tools on /3d as a tool for the fixed pump assembly,
    HSM-000161.
    Derek: "Number all. Those are parts we make to make other parts we make. They need part numbers."
    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
2026-11-03 Give every body in the machine and the cold core a part number
    Every named body in the soda machine, the cold core, both faucet styles
    and the magnetic float assembly now maps to a part number.
    The parts that had none take these:
    - the four rear equipment snap caps (HSM-000448 to HSM-000451) and the
    G Ganen pump snap cap (HSM-000455), PET-GF
    - the reservoir B fill bend holder (HSM-000454)
    - the flavor reservoir gasket, tube grip and air-tube grip (HSM-000456
    to HSM-000458), TPU 90A
    - the carbonator upper float stop (HSM-000459)
    - the GAGIRA reducing coupling (HSM-000452), the John Guest PI4512F6S
    flare adapter (HSM-000453) and PP061208W reducer (HSM-000460)
    - the reinforced PVC pump s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
2026-11-03 Give each tube the cold core pots one number
    Seven tubes are potted through the cold core and run on past the lid with
    no fitting between: the water inlet, the CO2 inlet, the carbonated-water
    riser and the four reservoir draw and fill tubes. Each carried two numbers,
    one for the potted span and one for the free end. Each is now one cold-core
    part under the machine-side number. A binding that begins "../" names the
    free end the machine's model draws, and each cost tag adds the two spans'
    weights. Every body in the machine and the cold core still maps.
    Co-Authored-By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
2026-11-03 Drop the three tubes the machine no longer has
    The PISCO regulator's inlet neck passes the CO2 hole, the ACVUS-44 stem
    check fits straight into its outlet, and the pump's discharge check plugs
    into its reducer: the routing makes co2-0, co2-1 and water-6 as mates with
    no tube. Their records, BOM lines and cost tags are gone. HSM-000286 is the
    111.9 mm link after the V-B outlet elbow, and the 33.1 mm cross before it is
    HSM-000463, so 286's tag weighs its own length instead of the whole run.
    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
2026-11-03 Number the umbilical drain once, as the faucet's drain tube
    The vent's drain return leaves the machine's drain bulkhead as the
    continuous 1,871 mm faucet drain, HSM-000108. The machine listed the same
    tube a second time as a vent-return umbilical tube. It now binds the
    outboard stub the enclosure draws to HSM-000108 through a used-with
    relation, as it does the install-kit tubes, and that duplicate number and
    its BOM line are gone.
    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
2026-11-03 Take the pump's foot screws and washers off the machine
    The G Ganen's rubber feet and their legs slide off, and the bare pump sits
    in the lid's half pipe under its snap cap, so the four M3 x 20 screws
    through the feet and their four washers are not in the machine. Their BOM
    lines and records are gone; neither had a purchase or a cost row.
    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
2026-11-03 Move physical model, presentation and viewer exports into Rust
    Stream fine model references and installed frames without Python CAD objects.
    Keep paired producer surfaces, explicit glyph component names, exact scene buffers
    and replaceable wiring STEP/payload records in the machine export program.
    Session: 01a1a04e-ad5f-7160-a8db-e56dddcc8bef
    Derek: "I'm willing to place a bet on rust here, and it seems like agents are not
    taking that seriously, and are testing every single damn change incrementally
    instead of doing more at once and just trusting that even if we're not faster in
    rust on the first try, we can probably iterate to faster there, for the most part,
    and for the rare case wher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
2026-11-03 Move the machine equipment and warm route inputs onto Rust models
    Place source-bound fine references, construct the installed joints and hardware
    on the kernel, and pass scalar route/port data to the machine placement and
    route programs. Retain source presentation bindings and omit Python CAD objects.
    Use Spade's underflow mitigation for projected cap triangulation coordinates.
    Session: 01a1a04f-2e06-7dd2-aa53-7853109323ea
    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
2026-11-03 Run cold-core and faucet print consumers in Rust
    Use the print program for bounded and full-triangle surfaces, retaining STEP
    identity/source binding and the existing family aliases. Recover graft frames in
    Rust and hand explicit references to the machine exporter. Keep legacy mesh-list
    readers and manual consumer APIs while normal family wrappers avoid loading
    NumPy, trimesh or CAD libraries.
    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
2026-11-03 Restore build artifacts through the public object origin
    Read R2_PUBLIC_URL before the app proxy and retained release fallbacks, after the
    existing local/authenticated store paths. Configure the public object origin for
    derive's restore step without adding credentials or changing artifact membership.
    The private HTTP fixture restores catalog and build-only bytes with the app proxy
    unavailable, preserves ordinary website filtering, and exercises the retained
    object and archive fallbacks.
    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
2026-11-03 Plan parallel Rust speed pieces and scoped native removal
    Describe the current Rust program speed pieces, fixed-input warm process
    measurements and the two-driver native removal boundary.
    Derek: "Yes"
    Derek: "Removed"
    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
2026-11-03 Remove native enclosure construction paths
    Keep the enclosure and machine entry points on their Rust drivers, and retain scalar dimensions, Box/Pack records, port and anchor data helpers, construction recipes and existing check questions. Remove native geometry builders, drawings/exporters and native selection flags from the two drivers. Numeric contexts bind their existing operation slots; recorded half geometry replaces the native half fallback.
    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
2026-11-03 Reuse physical export sources and finalize the fine archive in place
    Keep each immutable source archive across reference planning, numeric copying and
    presentation selection, releasing it after its final use. Attach the finished
    presentation document over the initial ZIP directory without recopying numeric
    members. Other export operations keep their existing binding path.
    All current 438-body STEP, fine archive and presentation bytes are exact, as are
    the journaled input identities. The single warm timed pair before the final ZIP
    cursor repair took 64.670 s for control and 66.302 s for candidate. Candidate
    footprint was 83.7 MB higher and sampled RSS 58 MB lower. The final cursor repair
    was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
2026-11-03 Decode imported model geometry directly into rows
    Read vertex and triangle scalars into their final owned row buffers. Track the
    existing coordinate finiteness result during decoding and keep its reporting
    point, NPY type conversion, read-error precedence, dimensions, selected visits,
    face records and callback behavior.
    Derek: "even if we're not faster in rust on the first try, we can probably iterate to faster there, for the most part"
    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
2026-11-03 Number the CO2 inlet collet with the PISCO; the reservoir gasket is 85A
    The machine's co2-inlet body is the PISCO RVFUP regulator's own inlet
    release collet. The approved ASSE layout passes the regulator's long
    neck through a hole of its own (rear-port-rebuild/README.md), and
    rear_plumbing.py draws the collet from the regulator's native model, so
    the body is bound to HSM-000331 with the rest of the regulator.
    HSM-000054, the neoFit ABU44-E bulkhead that layout replaced, is not in
    the machine: its record, its BOM line, which also named a co2-inlet-nut
    the model no longer has, and the collet press's relation to it are gone.
    The reservoir gasket is TPU 85A. reservoir.py has called for 85A sinc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
2026-11-03 Publish catalog membership changes without recutting geometry
    Reconcile the numbered website projection when stored bytes and producer
    inputs are unchanged, and notify the running site after that projection
    is published. Keep the hand-run publisher fixture self-contained.
    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
2026-11-03 Carry the current verified Rust assembly and drawing bindings
    Carry declared outputs from the passing affected build, preserving authored
    text and physical records. Geometry and fit answers remain exact; the
    physical model binds its own drawing and installed exports include wiring.
    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
2026-11-03 Route the CO2 tether into the PISCO's inlet collet; reservoir gaskets are 85A
    bom.md's primary-regulator row and the burn-in guide run the gas through
    the PISCO secondary, whose own inlet neck crosses the rear wall, as the
    approved ASSE layout has it: the tether pushes into that inlet collet,
    and the ACVUS44 stem check sits in the PISCO's outlet. bom.md bills the
    two reservoir gaskets to TPU 85A stock, as reservoir.py specifies and
    every print of them ran.
    Derek: "Fix them"
    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
2026-11-03 The CO2 tether lands in the PISCO's inlet collet in four more docs
    The enclosure procedure's BOM pointer, the ship-cap list, the Taprite
    reference and the rear caps' README named the retired ABU44 bulkhead.
    Derek: "Fix them too"
    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
2026-11-03 Bound installation guide filter surfaces to the captured picture
    Use an explicit SVG user-space filter region with the existing sampling
    margin. Capture diagnostics name each job, region and failing phase on
    stderr, and a failed capture discards its occupied browser immediately.
    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
2026-11-03 Port plate part numbers show the tiles the machine installs
    HSM-000062 through HSM-000067 named bulkhead_ring.py's standalone plates:
    2 mm pocket chips, the CO2 one still bored for the ABU44's Ø17.3 barrel.
    The machine installs and prints rear_identification's 1.8 mm channel
    tiles, the CO2 one bored Ø13.857 on the PISCO's axis. Each record now
    names its rear-label STEP, with the rear-identification README as its
    part details.
    Derek: "Please fix that as well. Stop telling me about small broken things and just fix them."
    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
2026-11-03 The drill-down's fallbacks name what the rear ports install
    The six tile aliases named bulkhead_ring.py's superseded plates,
    bulkhead-water named the JG union in place of the PP010822E, and
    co2-inlet named the retired ABU44 in place of the PISCO it is the inlet
    collet of. The catalog answers first for each of them; these are the
    files the viewer falls back to.
    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
2026-11-03 Show numbered rear identification tiles on the website
    Project the current catalog onto the existing verified store objects.
    All eighteen newly exposed STEP, presentation and print files passed
    actual download/decompression SHA256 verification. Retain every build-store
    member, model fingerprint and physical record without a rebuild or upload.
    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
2026-11-03 Put snap release access in receivers and preserve the fitted hardware seats
    Session: Coordinator 2
    Derek: "I don't need a screwdriver hole in the wing tips. I need screwdriver holes in the receiver."
    Derek: "Just need to make sure that it's actually possible."
    Derek: "I'd like it to conform to the hex. I can ensure it lands at the right spot."
2026-11-03 Publish receiver tool access and the fitted snap set
    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
2026-11-03 Publish finished receiver openings and the ready replacement plate
    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
2026-11-03 Let a wrapped Bazel build run two heavy actions at once
    The combined normal build after the Rust speed batch ran its 70 genrules
    one at a time: 788 s elapsed against a 439 s critical path, with the CPU
    averaging 3.4 of 8 cores. Admission, the memory and swap limits and the
    four host slots are unchanged.
    Session: Rust conversion status and contribution plan
    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
2026-11-04 Keep print preparation bound to retired generator sources
    Read the retired CAD generators from their exact retained Git revision
    while checking live production inputs and mesh hashes on disk. Keep every
    slicer command, CLI option and existing integrity assertion. The low-force
    trial reader uses its recorded mesh clearances without importing CAD.
    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
2026-11-04 Remove native construction paths from cold-core drivers
    Keep the eight cold-core entry points on their Rust programs and retain their numeric recipes, scalar datums, colors, placements and existing Rust-measured reports. Remove native builders, geometry-readback branches and native CLI selection. Material bindings use the same scalar providers directly. The existing float sweep and reservoir print-source coupling remain intact.
    Derek's Yes applies to removing the remaining inventoried native CadQuery tools while retaining parts and Rust paths and excluding slicer, project and report flags. The reservoir print consumer's direct native import is a separately coordinated follow-up using the em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
2026-11-04 plumbing: remove native shared construction paths
    Retain the above-core reference interfaces, routing recipes, port frames and rear snap datums. Compute the reducer port directly from its authored frame and leave normal Rust drain reporting intact.
    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
2026-11-04 Remove retired reference native callers
    Retain joint numeric profiles and port frames, and water-split numeric clearance
    bounds. Retire native construction/check callers and the manual rear-clamp CAD
    reader while keeping its qualification record. Defer G Ganen CAD imports to its
    existing construction functions so the scalar profile API imports independently.
    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
2026-11-04 Retire native CAD fixture builders
    Keep the existing Rust generators, numeric recipes and document interfaces.
    Remove alternate native builders and their native-only self-test commands.
    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
2026-11-04 Retire remaining native cold-core review commands
    Preserve the generated models, BREP fixtures, qualification results and print
    records. The seven manual commands depend on native CAD construction and have
    no independent fine-model or Rust route.
    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
2026-11-04 Describe the Rust cold-core and retained print interfaces
    Remove instructions for deleted native builders and identify the retained review source in Git. Part dimensions, qualification records and numeric source bindings remain the existing build contracts.
    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
2026-11-04 Retire the enclosure iso line-art studies
    The SVG snapshots, the Blender helpers that cut them and the Freestyle
    visibility sieve leave the tree. The archive-finished-trials tag holds
    the complete set, scripts included, and hardware/README.md points there.
    .gitattributes, the input tracer's ELSEWHERE list and the dev server's
    comments no longer name them.
    Derek: "Yes, retire them"
    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
2026-11-04 Record the remaining work for the four complete production prints
    Bind the requested parts to their current STL hashes and fresh seven-class
    surface readings. Record stale reinforcement bindings and the deferred pump-well
    meeting-plane cleanup. Keep current snap approval and full-part manufacturing
    release as separate conclusions in this manual readiness assessment.
    Derek: "Like everything is good to go?"
    Derek: "I want to make sure you have put "ready for customer" level effort into making it actually ready not just a rough draft throwaway test print."
    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
2026-11-04 Render installation-guide contours without browser capture
    Rasterize the guide's SVG contours with the installed librsvg tool, including
    its PNG inputs, and expose only completed images to the compositor's cache.
    Regenerate the guide and print-order bundle with the native renderer.
    Report failed build targets after processing successful derived outputs so a
    partial build does not finish with a green workflow badge.
    Validation: rendered all 29 illustrations and reviewed all 34 reading pages;
    Small Landscape print preflight passed. Failed SVG conversion leaves no
    cached or temporary image.
    Session: Cloud
    Derek: "Okay, please fix it."
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2026-11-04 Publish the rear label-channel print finish
    Publish the corrected print skin in both complete viewer hosts, retaining the native back-top and installation geometry.
    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
2026-11-04 Avoid empty writes after complete descriptor frames
    A fast broker or engine can reply and close after receiving the first write.
    Send a continuation only when sendmsg left bytes outstanding, so an empty
    second write cannot turn a valid reply into BrokenPipeError.
    The socketpair regressions reproduce immediate peer closure and exercise both
    complete and partial writes with descriptor transfer through both clients.
    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
2026-11-04 Align the ASSE adapter and restore the rear receiver bases
    Derek: "So you have a printer free, please make whatever fix you can to the ASSE adapter position."
    Derek: "Please just remove those. That type of screw hole release does not work."
    Derek: "please pick a good print to get started on our printer that is now free."
    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
2026-11-04 Publish the aligned ASSE and continuous rear receiver bases
    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
2026-11-04 Prepare full parts with continuous receiver bases and record the front-top launch
    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
2026-11-04 Record the scanned rear-plumbing references in the change feed
    Derek: "I've got the 1/4 bulkhead sprayed and puttied and rotating and focused for you in revoscan to scan and create us a new model from that scan and implement in our assembly on the back of our enclosure thanks."
    Derek: "I've got the stem check putted and rotating and framed next for you here. Same procedure. Model and implement. Please be sure to clean up when you're done, disk space is tight here."
    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
2026-11-04 Balance rear connection cards and update the install guide
    Use 42 by 38 mm cards with square visible faces, place OVER below SODA and
    both FLAVOR ports in the right column, and center the nameplate below them.
    Carry the raised rows into the approved snaps, roof headroom, inlet header,
    soda holder and rear tube routes. Preserve the fitted cap profiles.
    Refresh the owner booklet's rear illustrations and connection instructions,
    and describe the current assembly and service sequence.
    Session: Fit
    Derek: "Please implement it. Feel free to place the nameplate as you see fit as well."
    Derek: "And update the install guide as well."
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
